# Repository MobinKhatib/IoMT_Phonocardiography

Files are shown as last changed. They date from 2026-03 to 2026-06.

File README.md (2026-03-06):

# IoMT_Phonocardiography
Laboratory of Internet of Medical Things

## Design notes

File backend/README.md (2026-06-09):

# PCG BLE Client

Python client for collecting phonocardiogram (PCG) data from Arduino via BLE.

## Installation

```bash
python3 -m venv venv
source venv/bin/activate
pip install -r requirements.txt
```

## Usage

```python
import asyncio
from pcg_ble_client import PCGClient

async def main():
    client = PCGClient(device_name="PCG_Monitor_Raw")
    await client.connect()

    # Collect 60 seconds of data
    async for batch in client.analyze(sample_rate=500, oversample_count=8, batch_size=6,
                               patient_name="John", analysis_time_seconds=60):
        print(f"Got batch: {batch}")

    # Get full accumulated signal
    signal = client.get_full_signal()

    await client.disconnect()

asyncio.run(main())
```

## API

### `PCGClient`

#### `connect()`
Establish BLE connection to Arduino.

#### `disconnect()`
Close BLE connection.

#### `is_connected() -> bool`
Check connection status.

#### `analyze(...) -> Generator[np.ndarray]`
Send analysis request and yield batches.

Parameters:
- `sample_rate` (int): Hz
- `oversample_count` (int): ADC reads per sample
- `batch_size` (int): Samples per BLE packet
- `patient_name` (str): Patient ID (truncated to 15 chars)
- `analysis_time_seconds` (int): Collection duration

Yields: `np.ndarray` of samples (uint16)

#### `get_full_signal() -> np.ndarray`
Return all accumulated samples (validated).

## Running Tests

```bash
python3 -m pytest tests/ -v
```

## Integration Tests

Integration tests require Arduino with `ble_lcd_analyzer.ino` flashed and powered.

```bash
pytest tests/test_integration.py -v -m "asyncio"
```

Note: Tests will skip if Arduino is not available.

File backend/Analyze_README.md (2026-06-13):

# PCG Analysis Pipeline (`pcg_pipeline.py`)

A Python pipeline that converts a raw WAV phonocardiogram (PCG) recording into structured, JSON-serialisable analysis data — covering signal cleaning, heart sound segmentation, cycle-level feature extraction, anomaly detection, and murmur grading.

---

## Table of contents

1. [What this pipeline does](#1-what-this-pipeline-does)
2. [Quick start](#2-quick-start)
3. [Dependencies](#3-dependencies)
4. [Configuration (`PCGConfig`)](#4-configuration-pcgconfig)
5. [Processing stages explained](#5-processing-stages-explained)
6. [Heart metrics explained](#6-heart-metrics-explained)
7. [Output schema](#7-output-schema)
8. [CLI usage](#8-cli-usage)
9. [WebUI integration](#9-webui-integration)
10. [Performance guidance](#10-performance-guidance)

---

## 1) What this pipeline does

`pcg_pipeline.py` takes a mono WAV file (typically 500 Hz, recorded from an ESP32 microphone) and runs it through five modules:

| Module | Output |
| --- | --- |
| Signal preprocessing | Clean, noise-reduced waveform |
| Envelope + peak detection | S1 and S2 heart sound locations |
| Segmentation | Sample-level labels: S1 / Systole / S2 / Diastole |
| Feature extraction + classification | Per-cycle metrics, rule-based checks, Isolation Forest anomaly scores |
| Murmur analysis | Per-cycle murmur flags and a summary assessment |

All outputs are plain Python types (no NumPy) so the returned dict can be passed directly to `json.dumps`.

---

## 2) Quick start

```python
from pcg_pipeline import run_pcg_pipeline, PCGConfig

result = run_pcg_pipeline(
    filename="/path/to/recording.wav",
    config=None,               # optional PCGConfig — defaults are fine for 500 Hz recordings
    save_filtered_wav=False,   # True → write <input>_filtered.wav to disk
    output_filename=None,      # custom path for the filtered WAV
    include_signals=False,     # True → add raw/filtered/envelope arrays to the result
)
```

Alias (identical behaviour):

```python
from pcg_pipeline import run_pipeline
result = run_pipeline("/path/to/recording.wav", include_signals=True)
```

---

## 3) Dependencies

```text
numpy
scipy
PyWavelets
librosa
scikit-learn
```

Install:

```bash
pip install numpy scipy PyWavelets librosa scikit-learn
```

---

## 4) Configuration (`PCGConfig`)

Pass a `PCGConfig` instance to override any default. Defaults are tuned for ESP32 recordings at 500 Hz.

| Field | Default | Meaning |
| --- | --- | --- |
| `lowcut` | `25.0` | Bandpass lower cutoff (Hz) — captures the full S1 fundamental |
| `highcut` | `200.0` | Bandpass upper cutoff (Hz) — auto-clamped to `Nyquist - 1` |
| `notch_freqs` | `(50.0, 100.0, 150.0)` | Powerline hum frequencies to notch out (Hz) |
| `notch_q` | `35.0` | Q-factor for each notch (higher = narrower notch) |
| `filter_order` | `4` | Butterworth bandpass order |
| `wavelet` | `"db6"` | Wavelet family for DWT denoising |
| `wavelet_level` | `4` | Decomposition depth |
| `envelope_cutoff` | `8.0` | Lowpass cutoff for Shannon envelope smoothing (Hz) |
| `min_peak_dist` | `0.25` | Minimum time between detected peaks (seconds) |
| `bpm_min` | `40` | Physiological HR lower bound (reserved for future gating) |
| `bpm_max` | `200` | Physiological HR upper bound (reserved for future gating) |
| `normal_ranges` | see below | Rule-based physiological limits per metric |
| `murmur_grade_thresholds` | `[0.15, 0.30, 0.50, 0.70, 0.90]` | Energy-ratio thresholds for murmur grading |

Default `normal_ranges`:

```python
{
    "s1_duration_ms":  (50, 200),
    "s2_duration_ms":  (40, 150),
    "systolic_ms":     (150, 450),
    "diastolic_ms":    (150, 1200),
    "s1_s2_amp_ratio": (0.5, 3.0),
    "heart_rate_bpm":  (45, 180),
}
```

---

## 5) Processing stages explained

### Stage 1 — DC offset removal

```
data = data - mean(data)
```

Removes any constant voltage offset introduced by the ADC or BLE transmission path. Must happen before filtering to avoid distortion.

### Stage 2 — Multi-notch filter

Three narrow IIR notch filters are applied sequentially at 50 Hz, 100 Hz, and 150 Hz (fundamental powerline frequency plus its two lowest harmonics). Q = 35 keeps each notch very narrow so heart-sound energy at adjacent frequencies is untouched. Any notch above Nyquist is skipped automatically.

### Stage 3 — Bandpass filter (25–200 Hz)

A zero-phase 4th-order Butterworth bandpass keeps only the frequency range that contains S1 and S2 energy and rejects low-frequency motion artefacts and high-frequency noise above the heart-sound band. The upper cutoff is clamped to `Nyquist - 1` automatically.

### Stage 4 — Wavelet denoising

Daubechies-6 (db6) discrete wavelet transform, 4 levels. A soft threshold is applied to all detail coefficients using a scaled Donoho-Johnstone universal threshold:

```
uthresh = 0.6 × σ × sqrt(2 × log(N))
```

The scale factor 0.6 (versus the classical value of 1.0) is intentional: it preserves more fine structure in the heart sounds while still suppressing broadband noise. σ is estimated from the finest-level coefficients via MAD.

### Stage 5 — Savitzky-Golay smoothing

A window-11, polynomial-order-3 SG filter removes any residual sample-level jitter while preserving peak sharpness. Final output is `filtered`.

### Stage 6 — Shannon energy envelope

```
E[n] = -x[n]² · log(x[n]² + ε)
```

Shannon energy suppresses low-amplitude noise more aggressively than simple squaring and gives better S1/S2 contrast. The result is lowpass-filtered at 8 Hz to produce a smooth envelope.

### Stage 7 — Peak detection and S1/S2 classification

`scipy.signal.find_peaks` is applied to the envelope with an adaptive threshold at the 75th percentile. Peaks are then classified as S1 or S2 using the interval-ratio rule: systole (S1→S2) is always shorter than diastole (S2→next S1), so consecutive triplets of peaks are labelled by which gap is shorter.

### Stage 8 — Segmentation

Sample-level state labels (0=S1, 1=Systole, 2=S2, 3=Diastole) are assigned by:
- Growing S1/S2 boundaries outward from each peak to 40% of peak height
- Filling the gap between S1-end and the next S2-start as Systole (if < 400 ms)
- Filling the gap between S2-end and the next S1-start as Diastole

---

## 6) Heart metrics explained

This section describes every metric the pipeline produces and what it means clinically.

### 6.1 Timing intervals

| Metric | Key | Normal range | Meaning |
| --- | --- | --- | --- |
| S1 duration | `s1_duration_ms` | 50–200 ms | Width of the first heart sound. S1 is caused by closure of the mitral and tricuspid valves at the start of ventricular contraction. Too short can indicate a sharp, pathological snap; too long may suggest a prolonged closure sequence. |
| S2 duration | `s2_duration_ms` | 40–150 ms | Width of the second heart sound. S2 is caused by closure of the aortic and pulmonary valves at the end of systole. A split S2 (audible doubling) can appear as an abnormally long or double-peaked S2. |
| Systolic interval | `systolic_ms` | 150–450 ms | Time from S1 start to S2 start. This is the period of ventricular ejection. Normal adult systole at rest is ~300 ms. Prolonged systole may suggest impaired ventricular function. |
| Diastolic interval | `diastolic_ms` | 150–1200 ms | Time from S2 start to next S1 start. Diastole is the filling phase. It is longer than systole at normal resting heart rates and shortens as rate increases. Very short diastole at high heart rates may limit filling time. |
| Cycle duration | `cycle_duration_ms` | derived | Full S1-to-S1 period in ms. Reciprocal gives heart rate. |
| Heart rate | `heart_rate_bpm` | 45–180 bpm | Beats per minute derived from cycle duration. Normal adult resting range is 60–100 bpm. |
| S:D ratio | `sd_ratio` | ~0.4–0.7 | Systolic interval divided by diastolic interval. At 60 bpm this is roughly 0.5. Rising ratio (diastole shrinking relative to systole) occurs at high heart rates or with prolonged ventricular contraction. |

### 6.2 Amplitude features

| Metric | Key | Meaning |
| --- | --- | --- |
| S1 RMS | `s1_rms` | Root-mean-square amplitude of the S1 segment. Reflects how loud the mitral/tricuspid closure is in the recording. |
| S2 RMS | `s2_rms` | Root-mean-square amplitude of the S2 segment. |
| S1/S2 amplitude ratio | `s1_s2_amp_ratio` | S1 RMS divided by S2 RMS. Normal range 0.5–3.0. A ratio < 0.5 (S2 louder than S1) at the apex may indicate aortic regurgitation. A very high ratio may reflect a soft S2. |
| Energy concentration | `energy_concentration` | Fraction of the full-cycle energy contained in the S1 and S2 segments. A healthy heart concentrates energy in the valve closures; a murmur spreads energy into systole or diastole. |
| Systolic noise ratio | `sys_noise_ratio` | RMS of the systolic segment divided by S1 RMS. Low values (< 0.15) indicate a quiet systole. Elevated values suggest systolic murmur energy. |
| Diastolic noise ratio | `dia_noise_ratio` | RMS of the diastolic segment divided by S1 RMS. Same interpretation for the diastolic phase. |

### 6.3 Spectral and waveform shape features

| Metric | Key | Meaning |
| --- | --- | --- |
| S1/S2 zero-crossing rate | `s1_zcr`, `s2_zcr` | Rate of sign changes per sample. A high ZCR indicates a noisy or multi-component sound; a low ZCR indicates a smoother, more tonal segment. |
| S1/S2 excess kurtosis | `s1_kurtosis`, `s2_kurtosis` | Statistical "peakedness" of the amplitude distribution. A sharp impulsive sound (like a clean valve closure) has high kurtosis. Broad or noisy segments have lower kurtosis. |
| S1/S2 spectral centroid | `s1_centroid`, `s2_centroid` | Frequency-weighted centre of mass of the FFT magnitude spectrum (Hz). S1 typically centres around 50–100 Hz; S2 slightly higher. An elevated centroid may indicate high-frequency murmur contamination of the sound. |
| MFCC means | `mfcc_0` … `mfcc_7` | Mean of 8 Mel-frequency cepstral coefficients computed over the full cycle. MFCCs capture the spectral envelope shape and are used as input features for the Isolation Forest classifier. They do not have a direct single-value clinical interpretation but collectively encode the timbral character of the cycle. |

### 6.4 Heart rate variability (HRV)

Computed from the sequence of RR intervals (cycle durations) across the whole recording. Only cycles with durations between 300 ms and 1500 ms are included.

| Metric | Key | Meaning |
| --- | --- | --- |
| Mean heart rate | `heart_rate_mean_bpm` | Average BPM across valid cycles. |
| HR standard deviation | `heart_rate_std_bpm` | Beat-to-beat variability of heart rate (BPM). |
| SDNN | `sdnn_ms` | Standard deviation of all NN (normal-to-normal) intervals. Captures overall HRV. Values < 20 ms suggest reduced autonomic modulation. |
| RMSSD | `rmssd_ms` | Root mean square of successive RR differences. Reflects short-term, predominantly parasympathetic (vagal) variability. Healthy adults at rest typically show 20–60 ms. |
| pNN50 | `pnn50_pct` | Percentage of consecutive RR differences > 50 ms. A higher pNN50 indicates greater parasympathetic tone. |

### 6.5 Murmur grading

Each cardiac cycle is independently assessed for murmur energy.

**Detection**: the RMS of the systolic (or diastolic) interval is compared to S1 RMS. If the ratio exceeds the first threshold (0.15 by default) the cycle is flagged.

**Grading** uses an energy-ratio approximation of the Levine scale:

| Grade | Ratio range | Clinical description |
| --- | --- | --- |
| 0 | < 0.15 | No murmur |
| 1 | 0.15–0.30 | Barely audible, heard only in quiet conditions |
| 2 | 0.30–0.50 | Faint but clearly heard |
| 3 | 0.50–0.70 | Moderately loud |
| 4 | 0.70–0.90 | Loud |
| 5–6 | > 0.90 | Very loud, may be audible with stethoscope partially off chest |

**Murmur shape features** (computed when the segment is long enough):

- `sys_diamond`: `True` if the envelope of the systolic segment peaks in the middle quarter of the interval. A diamond (crescendo-decrescendo) shape is characteristic of aortic stenosis and other ejection murmurs.
- `dia_decrescendo`: `True` if the first quarter of the diastolic envelope is more than 1.5× louder than the last quarter. A decrescendo shape is characteristic of aortic regurgitation.

**Summary assessment** (from `murmur.assessment`):

| Condition | Text |
| --- | --- |
| > 50% cycles flagged in either phase | "Significant murmur activity …" |
| 20–50% cycles flagged | "Some murmur-like activity detected (may be recording noise)" |
| < 20% cycles flagged | "No significant murmur activity" |

### 6.6 Anomaly detection (Isolation Forest)

All per-cycle features (excluding the private `_start`/`_end` indices) are z-scored and fed to an Isolation Forest with 200 trees and a 15% contamination prior. Each cycle receives:

- `label`: `1` = normal, `-1` = anomaly
- `score`: decision function value (more negative = more anomalous)

An anomalous cycle does not necessarily mean disease — it may reflect a position shift during recording, a deep breath, or an ectopic beat. Use it as a flag for human review rather than a diagnosis.

---

## 7) Output schema

`run_pcg_pipeline(...)` returns a dict with these top-level keys.

### 7.1 `file_info`

```json
{
  "filename": "/path/to/recording.wav",
  "sample_rate_hz": 500,
  "nyquist_hz": 250.0,
  "duration_s": 23.0,
  "samples": 11510,
  "highcut_clamped": false,
  "effective_highcut_hz": 200.0
}
```

### 7.2 `config`

The full `PCGConfig` serialised as a dict, so the consumer knows exactly what parameters were used.

### 7.3 `peaks`

```json
{
  "total_peaks": 54,
  "s1_count": 31,
  "s2_count": 31,
  "peak_indices": [...],
  "s1_indices": [...],
  "s2_indices": [...],
  "peak_times_s": [...],
  "s1_times_s": [...],
  "s2_times_s": [...],
  "threshold": 0.042
}
```

### 7.4 `segmentation`

```json
{
  "state_names": ["S1", "Systole", "S2", "Diastole"],
  "states": [3, 3, 0, 0, 1, 1, ...],
  "segments": [
    {"state": "S1", "start_index": 120, "end_index": 164, "start_s": 0.24, "end_s": 0.328},
    ...
  ],
  "stats": {
    "S1":       {"count": 20, "mean_ms": 88.4, "std_ms": 26.2, "min_ms": 46, "max_ms": 128},
    "Systole":  {"count": 22, "mean_ms": 231.8, ...},
    "S2":       {"count": 28, "mean_ms": 85.3, ...},
    "Diastole": {"count": 29, "mean_ms": 474.6, ...}
  }
}
```

### 7.5 `classification`

```json
{
  "cycles": [
    {
      "s1_duration_ms": 98.0,
      "s2_duration_ms": 82.0,
      "systolic_ms": 302.0,
      "diastolic_ms": 520.0,
      "cycle_duration_ms": 820.0,
      "heart_rate_bpm": 73.2,
      "sd_ratio": 0.58,
      "s1_rms": 0.045,
      "s2_rms": 0.068,
      "s1_s2_amp_ratio": 0.66,
      "energy_concentration": 0.71,
      "s1_zcr": 0.32,
      "s2_zcr": 0.29,
      "s1_kurtosis": 2.1,
      "s2_kurtosis": 1.8,
      "s1_centroid": 78.4,
      "s2_centroid": 91.2,
      "sys_noise_ratio": 0.09,
      "dia_noise_ratio": 0.07,
      "mfcc_0": -12.4,
      "mfcc_1": 3.1,
      "...": "...",
      "_s1_start": 120, "_s1_end": 164,
      "_sys_start": 164, "_sys_end": 315,
      "_s2_start": 315, "_s2_end": 356,
      "_dia_start": 356, "_dia_end": 616
    }
  ],
  "rule_based": {
    "normal_cycles": 20,
    "flagged_cycles": 8,
    "flagged_details": [
      {"cycle_index": 0, "violations": ["s1_s2_amp_ratio=0.5 < 0.5"]}
    ]
  },
  "isolation_forest": {
    "feature_keys": ["s1_duration_ms", "s2_duration_ms", ...],
    "labels": [1, 1, -1, 1, ...],
    "scores": [0.08, 0.06, -0.05, ...],
    "normal_cycles": 23,
    "anomaly_cycles": 5,
    "score_min": -0.053,
    "score_max": 0.100
  },
  "per_cycle_stats": {
    "heart_rate_bpm": {"mean": 73.2, "std": 4.3, "min": 55.7, "max": 78.7},
    "...": "..."
  },
  "hrv_metrics": {
    "heart_rate_mean_bpm": 73.2,
    "heart_rate_std_bpm": 4.3,
    "sdnn_ms": 57.5,
    "rmssd_ms": 88.6,
    "pnn50_pct": 35.7
  }
}
```

`hrv_metrics` is `null` if fewer than 3 valid RR intervals are found.

Private keys (`_s1_start`, etc.) in each cycle dict hold sample indices for span rendering. They are not included in the Isolation Forest feature matrix.

### 7.6 `murmur`

```json
{
  "analysis_range_hz": [0.0, 250.0],
  "systolic_murmur_cycles": 7,
  "diastolic_murmur_cycles": 8,
  "total_cycles": 28,
  "systolic_pct": 25.0,
  "diastolic_pct": 28.6,
  "assessment": "Some murmur-like activity detected (may be recording noise)",
  "cycle_results": [
    {
      "systolic_murmur": true,
      "diastolic_murmur": false,
      "systolic_grade": 1,
      "diastolic_grade": 0,
      "systolic_ratio": 0.19,
      "diastolic_ratio": 0.08,
      "sys_diamond": false
    }
  ]
}
```

`sys_diamond` and `dia_decrescendo` only appear when the respective segment is long enough to compute them.

### 7.7 `exports`

```json
{
  "saved_filtered_wav": "/path/to/recording_filtered.wav"
}
```

`null` when `save_filtered_wav=False`.

### 7.8 `signals` (optional, `include_signals=True` only)

```json
{
  "time_axis_s": [...],
  "raw": [...],
  "filtered": [...],
  "filtered_normalized": [...],
  "envelope": [...]
}
```

---

## 8) CLI usage

```bash
cd Analysis
python pcg_pipeline.py /path/to/recording.wav
python pcg_pipeline.py /path/to/recording.wav --save-filtered
python pcg_pipeline.py /path/to/recording.wav --include-signals
```

Output is printed as indented JSON to stdout.

---

## 9) WebUI integration

### Backend

1. Receive WAV upload, save to a temp file.
2. Call `run_pcg_pipeline(filename, include_signals=True)`.
3. Return JSON to frontend.

Use `include_signals=False` for a lightweight summary endpoint and `include_signals=True` for a full chart endpoint.

### Frontend chart layers

| Plot | x-axis | y / spans |
| --- | --- | --- |
| Waveform + envelope | `signals.time_axis_s` | `signals.filtered` and `signals.envelope` |
| S1/S2 markers | `peaks.s1_times_s`, `peaks.s2_times_s` | points on envelope |
| Segmentation | `segmentation.segments[i].start_s` → `end_s` | coloured spans: S1=red, Systole=orange, S2=blue, Diastole=green |
| Anomaly overlay | `cycles[i]._s1_start / sample_rate` → `_dia_end / sample_rate` | green (label=1) or red (label=-1) |
| Murmur overlay | `cycles[i]._sys_start / sample_rate` → `_sys_end / sample_rate` | red when `systolic_murmur=true` |
| Murmur overlay | `cycles[i]._dia_start / sample_rate` → `_dia_end / sample_rate` | purple when `diastolic_murmur=true` |

---

## 10) Performance guidance

Long recordings produce large signal arrays. Downsample only the waveform for display; keep all event data at full precision.

```python
import numpy as np

def decimate_xy(x, y, max_points=3000):
    n = len(x)
    if n <= max_points:
        return x, y
    idx = np.linspace(0, n - 1, max_points, dtype=int)
    return [x[i] for i in idx], [y[i] for i in idx]
```

Target 2 000–5 000 points per chart line. All segment/peak/label arrays can remain at full length since they are small.

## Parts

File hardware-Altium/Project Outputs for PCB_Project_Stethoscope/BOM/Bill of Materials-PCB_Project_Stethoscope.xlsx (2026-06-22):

Line # | Name | Description | Designator | Quantity | Manufacturer 1 | Manufacturer Part Number 1 | Manufacturer Lifecycle 1 | Supplier 1 | Supplier Part Number 1 | Supplier Unit Price 1 | Supplier Subtotal 1
 | 100u | capacitor | C1 | 1 | Panasonic | EEEFTH100UAR | Volume Production | RS | 7296283P | 0.13308 | 13.31
 | 10u | capacitor | C2 | 1 | KYOCERA AVX | 1206ZD106KAT2A | Volume Production | Avnet | KGM31HR51A106KU | 0.32544 | 650.88
 | MDOB048064AV-WI | LED | IC1 | 1 | Midas | MDOB048064AV-WI |  | Farnell | MDOB048064AV-WI | 11.12 | 11.12
 | JST-PH 2-pin Battery Connector | JST-PH 2-pin LiPo Battery Connector | J1 | 1 | Adafruit Industries | 4714 |  | DigiKey | 1528-4714-ND | 0.95 | 0.95
 | 2.2k | Resistor | R1, R2 | 2 | KOA Speer | RN73R2ATTD2201B10 | Volume Production | RS | 2050472 | 0.80307 | 8.03
 | Arduino Nano ESP 32 |  | U1 | 1 | Arduino | ABX00092 |  | Farnell | ABX00092 | 18.17 | 18.17
 | SEN-14262 | Audio sensor | U2 | 1 | SparkFun | SEN-14262 |  | Arrow Electronics | SEN-14262
 | USB-C Charger Module | ADAFRUIT 4410 MICROLIPO USBC MODULE | U3 | 1 | Adafruit Industries | 4410 |  | DigiKey | 1528-4410-ND | 5.95 | 5.95

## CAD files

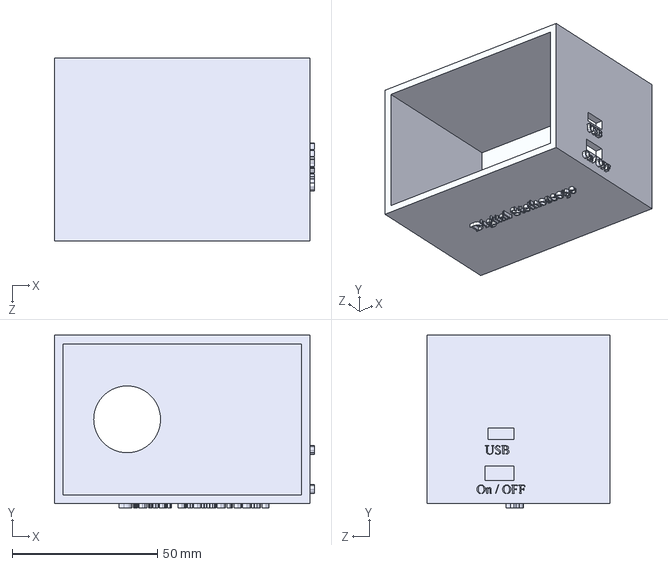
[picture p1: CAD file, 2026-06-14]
design/Digital Stethoscope Box3D/Part1.STEP
89.5 x 59.5 x 63.0 mm

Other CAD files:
design/Digital Stethoscope Box3D/Part1.SLDPRT
design/Digital Stethoscope Box3D/Part1.STL
design/Digital Stethoscope Box3D/Part2.SLDPRT
design/Digital Stethoscope Box3D/Part2.STL

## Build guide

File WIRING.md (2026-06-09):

# Arduino Nano ESP32 Wiring Guide

## Components Required

| Component | Part Number | Notes |
|---|---|---|
| Arduino Nano ESP32 | AE-ESP32-S3 | Main microcontroller |
| OLED Display | SSD1306 48x64 | I2C interface |
| LiPo Battery | 3.7V or 4.2V | Recommended 2000-5000 mAh |
| Phonocardiography Sensor | Analog output | ADC input |
| Resistor 2.2kΩ | (2x) | Battery voltage divider |
| Resistor 2.2kΩ | 1x | Optional pull-up for sensor |
| Capacitor 100µF | 1x | Power supply decoupling |
| Capacitor 10µF | 1x | Filter for battery line |

---

## Pinout Reference (Arduino Nano ESP32)

```
┌──────────────────────────────────────────┐
│      ARDUINO NANO ESP32 (Top View)       │
├──────────────────────────────────────────┤
│  D0/RX   GND   RESET  AREF   A0         │
│  D1/TX   GND    VIN    3V3   A1         │
│                                          │
│  D2      D3     D4     D5    D6          │
│  D7      D8     D9    D10   D11          │
│                                          │
│  D12    D13    GND    5V    RST          │
│  A2     A3    A4/SDA  A5/SCL            │
│         A6     A7     GND               │
│                                          │
│ I2C Default: SDA=A4(pin12)  SCL=A5(pin13)
│ Signal Input: A0 (pin19)                │
│ Battery Input: A1 (pin20)               │
└──────────────────────────────────────────┘
```

---

## Connection Diagram

### 1. OLED Display (SSD1306 I2C)

**Display Pins (Arduino Nano ESP32):**
- **GND** → Arduino Nano ESP32 GND
- **VCC** → Arduino Nano ESP32 3V3
- **SCL** → Arduino Nano ESP32 **A5** (pin 13)
- **SDA** → Arduino Nano ESP32 **A4** (pin 12)

```
     ┌──────────────────────┐
     │   SSD1306 OLED       │
     │   (48x64 pixels)     │
     └──────────────────────┘
            │    │    │    │
           GND  VCC  SCL  SDA
            │    │    │    │
            ↓    ↓    ↓    ↓
        GND  3V3 D4   D5
        ESP32 NANO
```

**Schematic Detail:**
```
3V3 ──────┬────────→ VCC (OLED)
          │
        100µF cap (ground other end)
          │
        GND

D4 (GPIO4/SCL) ──→ SCL (OLED)
D5 (GPIO5/SDA) ──→ SDA (OLED)

GND ──→ GND (OLED)
```

---

### 2. Battery Voltage Monitor (A0)

**Setup: 2:1 Voltage Divider**
- Monitor battery voltage to calculate percentage
- Supports 3.3V to 4.2V (LiPo) range
- **SEPARATE from signal input** (A0 dedicated to battery only)

```
        LiPo Battery (4.2V max)
        │
        │ (+ terminal)
        ├──────────────────→ (to system power, ~5V input)
        │
        ├──[2.2kΩ resistor]──┬──→ A0 (ADC, Battery Monitor)
        │                     │
        └────────────────────┴──[2.2kΩ resistor]──→ GND
                             │
                         (midpoint = A0 input)
```

**Voltage Divider Math:**
- Vin = 4.2V (fully charged LiPo)
- Vout = Vin × (R2 / (R1 + R2)) = 4.2 × (2.2k / 4.4k) = 2.1V
- ADC reads 2.1V at 12-bit resolution: (2.1 / 3.3) × 4095 ≈ 2613 counts
- Code maps: 3.3V (0%) → 4.2V (100%)

**Capacity Calculation (in code):**
```cpp
uint32_t mv = analogReadMilliVolts(A0);
mv /= 16;  // Average 16 samples
float vbat = mv * 2.0 / 1000.0;  // × 2 for divider
int pct = (int)((vbat - 3.3) / (4.2 - 3.3) * 100.0);
```

---

### 3. Phonocardiography Sensor Input (A1)

**Analog Signal Path:**
- **Sensor Output** → 10µF capacitor → **A1** (separate from battery A0)
- Optional: 2.2kΩ pull-up to 3V3 for impedance matching

```
    Phonocardiography Sensor
    (analog output, 0-3.3V)
           │
           ├──[10µF cap]──┬──→ A1 (ADC, Signal Input)
           │              │
           └──────────────┴──→ GND
                          
    (Optional pull-up for high-impedance sensors)
           ├──[2.2kΩ]──→ 3V3
```

**Why separate pins?**
- A0 dedicated to battery monitoring (always active)
- A1 dedicated to signal sampling (during analysis)
- Prevents interference between battery and signal readings

**ADC Configuration (in code):**
```cpp
analogReadResolution(12);  // 12-bit resolution (0-4095 counts)
```

---

## Full System Schematic

```
                    ┌─────────────────┐
                    │  LiPo Battery   │
                    │   3.7-4.2V      │
                    │ (2000-5000 mAh) │
                    └────────┬────────┘
                             │
                    ┌────────┴────────────────┐
                    │                         │
              [Voltage Divider]          [Power]
              (2.2k/2.2k)                 │
                    │                     │
                    ↓                     ↓
                  A0 (Battery)        +5V (VBAT)
                    │                     │
            ┌───────┴─────┬───────────────┴────────┐
            │             │                        │
        ┌─────────────────────────────────┐   ┌─────────────┐
        │     ESP32-S3 NANO               │   │   100µF     │
        │                                 │   │   Capacitor │
        │  D4 ──────────┬─────────────────┼───┤ (decouple)  │
        │  D5 ──────────┤                 │   └─────┬───────┘
        │               │ (I2C for OLED)  │         │
        │  A0 ←─ Battery Divider          │      GND
        │  A1 ←─ PCG Sensor               │
        │  3V3 ──────────┘                │
        │  GND ──────────────────┬────────┘
        │                        │
        └────────────┬───────────┘
                     │
        ┌────────────┴────────────┐
        │                         │
    ┌─────────────────┐   ┌──────────────────┐
    │  SSD1306 OLED   │   │  PCG Sensor      │
    │  (48x64 display)│   │  (Analog Out)    │
    │                 │   │                  │
    │  SCL ← D4       │   │  OUT ──[10µF]──┐ │
    │  SDA ← D5       │   │                 │ │
    │  VCC ← 3V3      │   │  GND ───────────┼─┘
    │  GND ─────────┐ │   │                 │
    │              │ │   │              GND
    └──────────────┼─┘   └────────┬────────┘
                  │                │
                  └────────┬───────┘
                           │
                  GND (common return)

Key: A0=Battery  A1=Signal  D4=SCL  D5=SDA
```

---

## Assembly Steps

1. **Battery Connection**
   - Connect LiPo + terminal → voltage divider upper end
   - Connect voltage divider center → A0
   - Connect voltage divider lower end → GND
   - Connect LiPo ground → ESP32 GND

2. **Power Decoupling**
   - 100µF capacitor across +5V and GND (near ESP32)
   - 10µF capacitor on sensor output (near A0)

3. **I2C Display (SSD1306)**
   - Connect SCL → GPIO4 (D4)
   - Connect SDA → GPIO5 (D5)
   - Connect 3V3 and GND

4. **Analog Sensor**
   - Connect sensor analog output through 10µF capacitor to A0
   - Ensure sensor is grounded to same GND

5. **Testing**
   - Flash `ble_lcd_analyzer.ino`
   - Check Serial Monitor (115200 baud)
   - Verify LCD shows battery % and "ADV" state
   - Confirm BLE device appears as "PCG_Monitor_Raw"

---

## Pin Usage Summary (Arduino Nano ESP32)

| Pin | Function | Used | Notes |
|-----|---|---|---|
| A0 (pin 19) | ADC Input | ✅ | Battery voltage divider (2:1) |
| A1 (pin 20) | ADC Input | ✅ | PCG sensor analog signal (10µF cap) |
| A4 (pin 12) | I2C SDA | ✅ | SSD1306 OLED display |
| A5 (pin 13) | I2C SCL | ✅ | SSD1306 OLED display |
| GND | Ground | ✅ | 2+ pins (battery, display, sensor) |
| 3V3 | Power 3.3V | ✅ | Display + logic |
| VIN/5V | Battery | ✅ | System power input |

---

## Power Budget

| Component | Current | Voltage | Power |
|---|---|---|---|
| ESP32-S3 | ~80 mA | 3.3V | 0.26W |
| OLED SSD1306 | ~10 mA | 3.3V | 0.03W |
| Sensor | ~5 mA | 3.3V | 0.02W |
| **Total** | **~95 mA** | **3.3V** | **~0.31W** |

**Runtime:** 2000 mAh battery ÷ 95 mA ≈ **21 hours** (nominal)

---

## Troubleshooting

**No Display:**
- Check I2C wiring (SDA/SCL swapped?)
- Verify 3V3 power to OLED
- Check Serial Monitor for I2C error messages

**No Sensor Data:**
- Verify A0 is not shorted
- Check sensor voltage is in 0-3.3V range
- Verify 10µF capacitor orientation (- to GND)

**Battery Reading Wrong:**
- Measure actual voltage at voltage divider midpoint
- Should be ~2.1V when battery is 4.2V
- Adjust resistor values if needed

**BLE Not Advertising:**
- Check Serial output: "BLE: Advertising started"
- Restart ESP32 if needed
- Ensure antenna connection (if external antenna model)

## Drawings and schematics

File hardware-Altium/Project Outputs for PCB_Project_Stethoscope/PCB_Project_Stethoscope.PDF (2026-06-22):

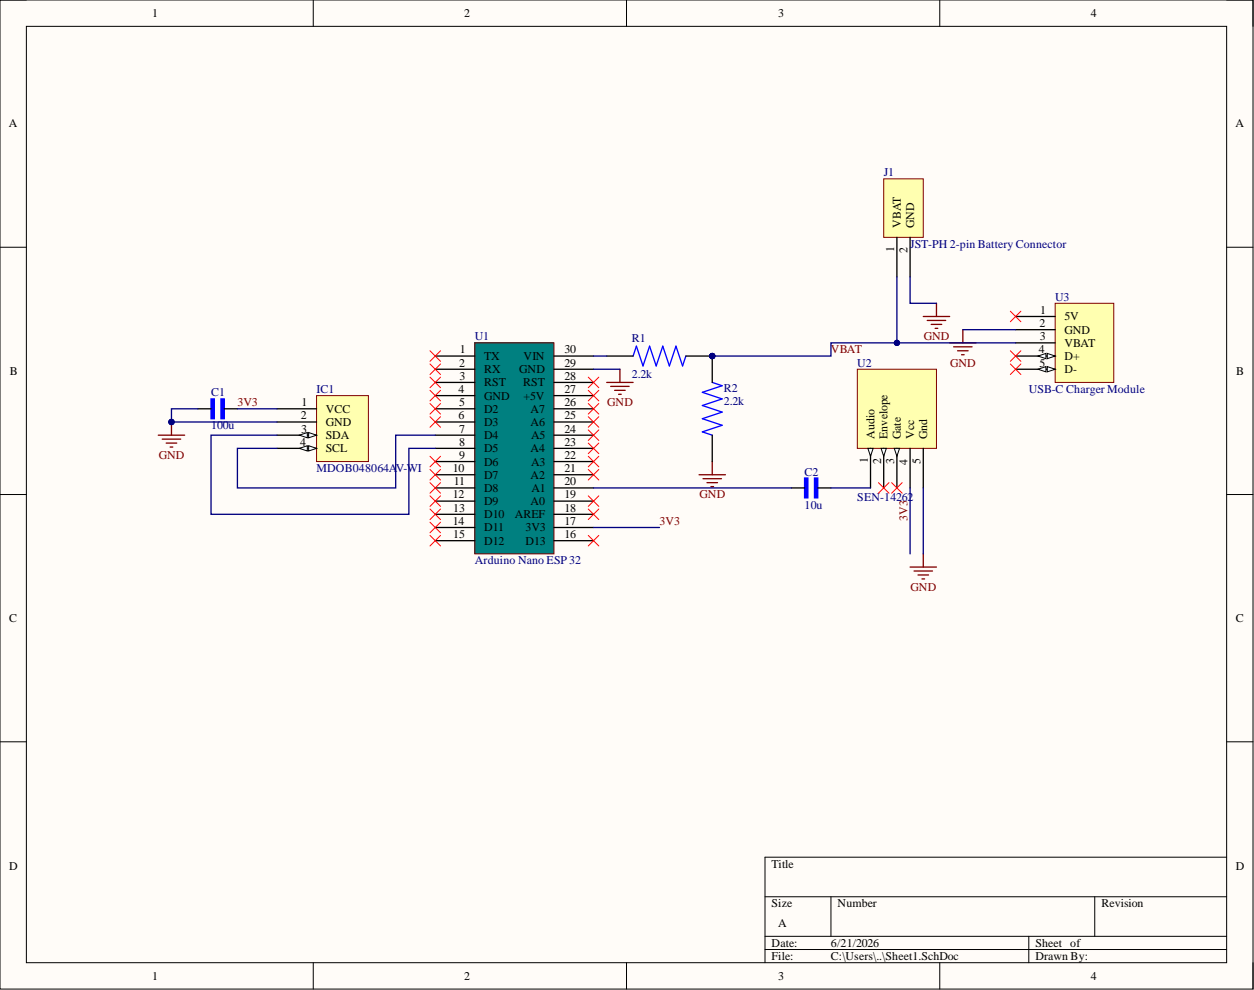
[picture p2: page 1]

JST-PH 2-pin Battery Connector

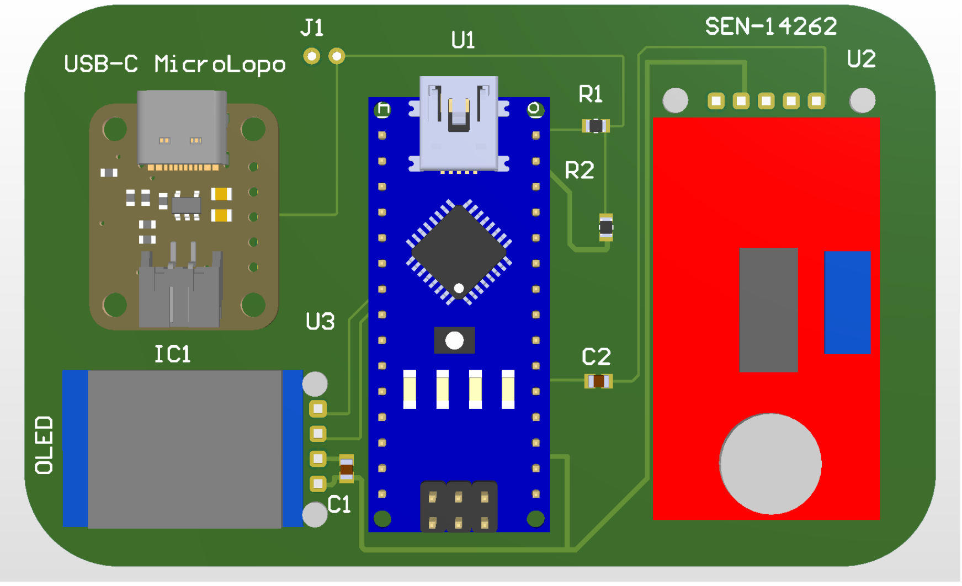
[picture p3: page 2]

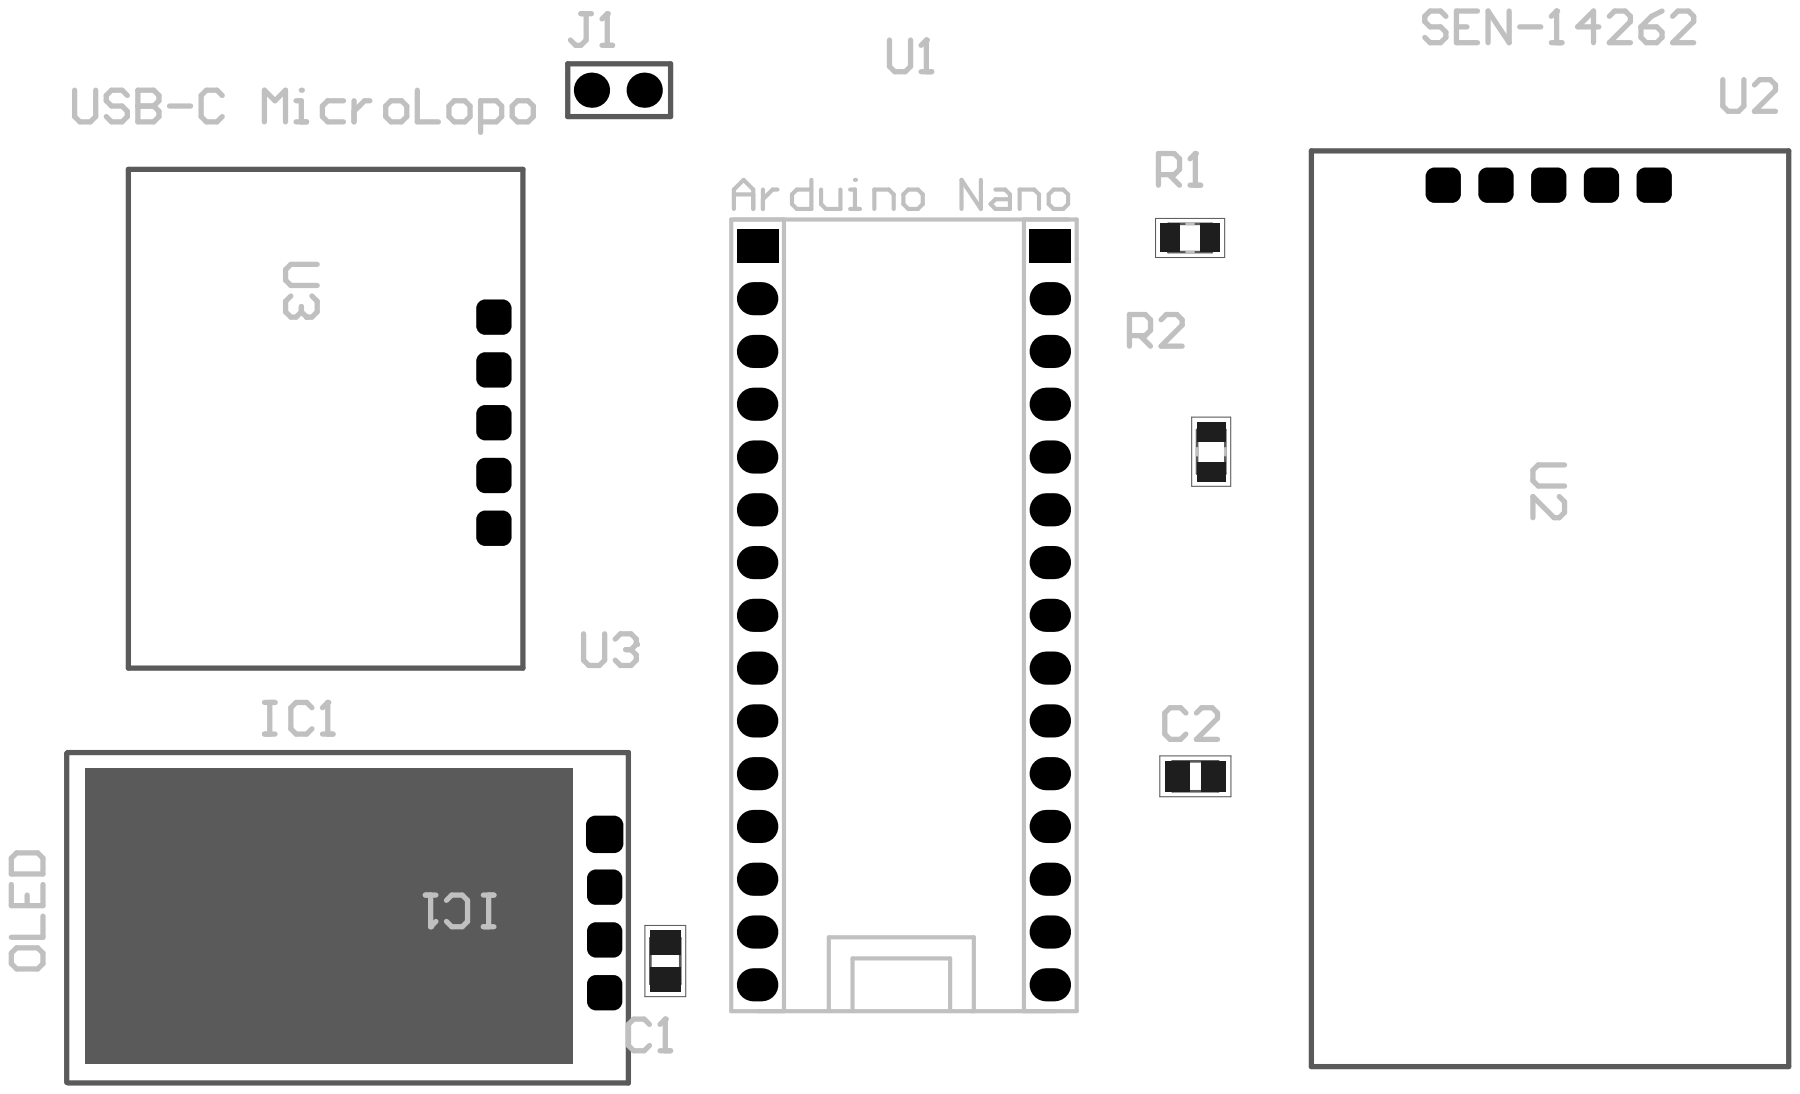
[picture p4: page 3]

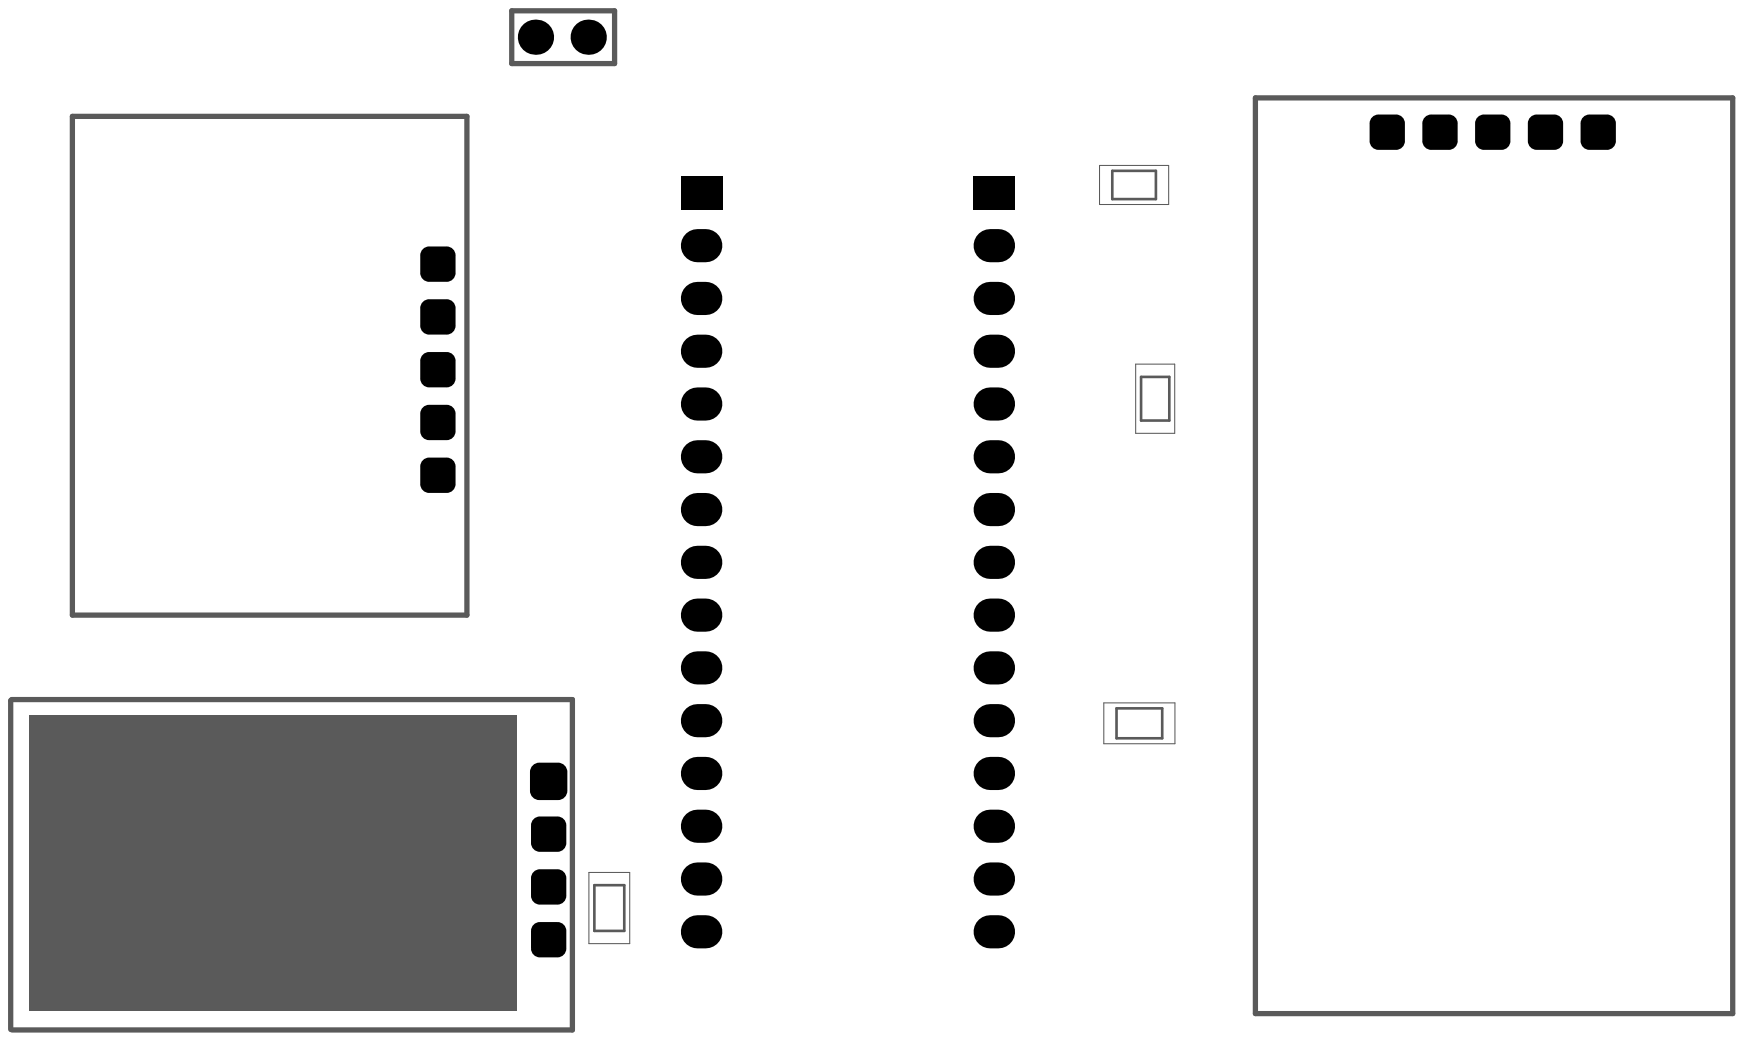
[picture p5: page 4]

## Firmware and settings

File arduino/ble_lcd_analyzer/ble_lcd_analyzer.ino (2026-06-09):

#include <BLEDevice.h>
#include <BLEServer.h>
#include <BLEUtils.h>
#include <BLE2902.h>
#include <U8g2lib.h>
#include <Wire.h>
#include <math.h>

// --- Configuration ---
const int BATTERY_PIN = A0;      // Battery voltage monitor (through divider)
const int SIGNAL_PIN = A1;       // PCG sensor analog input
const int TIMER_ID = 0;
const int TIMER_PRESCALER = 80;
const int TIMER_COUNT_UP = true;

// BLE UUIDs (from existing code)
#define SERVICE_UUID        "12345678-1234-1234-1234-123456789abc"
#define CHARACTERISTIC_UUID "abcd1234-ab12-cd34-ef56-123456789abc"

// Display (Arduino Nano ESP32: SCL=A5(pin13), SDA=A4(pin12))
U8G2_SSD1306_48X64_WINSTAR_F_HW_I2C u8g2(U8G2_R0, U8X8_PIN_NONE);

// --- State Machine ---
enum State {
  STATE_INITIALIZING,
  STATE_IDLE,
  STATE_CONNECTED,
  STATE_ANALYZING
};

State currentState = STATE_INITIALIZING;

// --- BLE ---
BLEServer* pServer = NULL;
BLECharacteristic* pCharacteristic = NULL;
bool deviceConnected = false;

// --- Sampling ---
#define MAX_BATCH_SIZE 6

// One completed batch of samples, passed from the sampling task to loop().
struct SampleBatch {
  uint16_t samples[MAX_BATCH_SIZE];
  uint8_t count;
};

hw_timer_t* timer = NULL;
TaskHandle_t samplingTaskHandle = NULL;
QueueHandle_t batchQueue = NULL;       // sampling task -> loop(); buffers batches so none are dropped
volatile bool resetSampling = false;   // signals the task to start a fresh run

int sampleRate = 500;
int oversampleCount = 8;
int batchSize = 6;
int analysisTimeSeconds = 60;
char patientName[16] = {0};

// --- Analysis Timer ---
unsigned long analysisStartTime = 0;
bool isAnalyzing = false;
bool shouldStartTimer = false;  // Flag to defer timer setup to main loop

// --- Battery Helper ---
int batteryPercent() {
  uint32_t mv = 0;
  for (int i = 0; i < 16; i++) mv += analogReadMilliVolts(BATTERY_PIN);
  mv /= 16;
  float vbat = mv * 2.0 / 1000.0;   // x2 for divider, mV -> V
  int pct = (int)((vbat - 3.3) / (4.2 - 3.3) * 100.0);
  return constrain(pct, 0, 100);
}

// --- Display Helpers ---
void drawBT(int cx, int ty) {
  int top = ty, bot = ty + 10, q1 = ty + 3, q3 = ty + 7;
  int r = cx + 3, l = cx - 3;
  u8g2.drawLine(cx, top, cx, bot);
  u8g2.drawLine(cx, top, r, q1);
  u8g2.drawLine(r, q1, l, q3);
  u8g2.drawLine(l, q1, r, q3);
  u8g2.drawLine(r, q3, cx, bot);
}

void drawCheck(int x, int y) {
  u8g2.drawLine(x, y + 2, x + 2, y + 4);
  u8g2.drawLine(x + 2, y + 4, x + 6, y - 1);
}

void textHighlight(int x, int y, int w, int h, const char* s, const uint8_t* font) {
  u8g2.drawBox(x, y, w, h);
  u8g2.setDrawColor(0);
  u8g2.setFont(font);
  u8g2.setCursor(x + 2, y + h - 2);
  u8g2.print(s);
  u8g2.setDrawColor(1);
}

void drawSpinner(int cx, int cy, int r) {
  u8g2.drawCircle(cx, cy, r);
  float a = millis() / 90.0;
  int sx = cx + (int)(cos(a) * r);
  int sy = cy + (int)(sin(a) * r);
  u8g2.drawDisc(sx, sy, 2);
}

void drawTopPanel() {
  u8g2.setFont(u8g2_font_5x7_tf);
  u8g2.setCursor(2, 10);
  u8g2.print("Bat:");
  u8g2.print(batteryPercent());
  u8g2.print("%");
  u8g2.drawHLine(0, 13, 48);
}

// --- Sampling Timer ISR ---
// IMPORTANT: On ESP32 you must NOT call analogRead() (or most driver/RTOS
// functions) from a hardware-timer ISR. analogRead() is not IRAM-safe and
// acquires locks, which aborts -> the board reboots the instant the timer
// fires. So the ISR only notifies the sampling task; the task does the reads.
void ARDUINO_ISR_ATTR onTimer() {
  BaseType_t higherPriorityTaskWoken = pdFALSE;
  vTaskNotifyGiveFromISR(samplingTaskHandle, &higherPriorityTaskWoken);
  portYIELD_FROM_ISR(higherPriorityTaskWoken);
}

// --- Sampling Task ---
// Runs in normal (non-ISR) context, so analogRead() is safe here. Wakes up
// once per timer tick, takes an oversampled reading, and fills the batch.
void samplingTask(void* param) {
  static SampleBatch batch;
  static int idx = 0;

  for (;;) {
    // Block until the timer ISR signals that it's time to take a sample.
    ulTaskNotifyTake(pdTRUE, portMAX_DELAY);

    // Start of a new analysis run: clear any partial batch and stale queue.
    if (resetSampling) {
      idx = 0;
      xQueueReset(batchQueue);
      resetSampling = false;
    }

    if (!isAnalyzing) {
      idx = 0;
      continue;
    }

    uint32_t sum = 0;
    for (int i = 0; i < oversampleCount; i++) {
      sum += analogRead(SIGNAL_PIN);  // Read from signal input, not battery
    }
    batch.samples[idx] = sum / oversampleCount;
    idx++;

    if (idx >= batchSize) {
      batch.count = batchSize;
      // Non-blocking hand-off to loop(). The queue buffers many batches so
      // samples are never dropped while loop() is busy with display or BLE.
      xQueueSend(batchQueue, &batch, 0);
      idx = 0;
    }
  }
}

// --- BLE Command Parsing ---
void parseStartCommand(uint8_t* data, size_t length) {
  if (length < 29) {
    Serial.println("BLE: Invalid packet length");
    return;
  }

  // Byte 0: command type (should be 0x01 for START)
  uint8_t cmdType = data[0];
  if (cmdType != 0x01) {
    Serial.println("BLE: Invalid command type");
    return;
  }

  // Bytes 1-4: SAMPLE_RATE (little-endian)
  sampleRate = (uint32_t)data[1] | ((uint32_t)data[2] << 8) | ((uint32_t)data[3] << 16) | ((uint32_t)data[4] << 24);
  sampleRate = constrain(sampleRate, 100, 5000);  // Limit to safe range

  // Bytes 5-6: OVERSAMPLE_COUNT (little-endian)
  oversampleCount = (uint16_t)data[5] | ((uint16_t)data[6] << 8);
  oversampleCount = constrain(oversampleCount, 1, 32);  // Limit to safe range

  // Bytes 7-8: BATCH_SIZE (little-endian)
  batchSize = (uint16_t)data[7] | ((uint16_t)data[8] << 8);
  batchSize = constrain(batchSize, 1, MAX_BATCH_SIZE);  // Limit to batch buffer size

  // Bytes 9-12: ANALYSIS_TIME_SECONDS (little-endian)
  analysisTimeSeconds = (uint32_t)data[9] | ((uint32_t)data[10] << 8) | ((uint32_t)data[11] << 16) | ((uint32_t)data[12] << 24);

  // Bytes 13-28: Patient name (null-terminated)
  memset(patientName, 0, sizeof(patientName));
  strncpy(patientName, (const char*)&data[13], 15);
  patientName[15] = '\0';

  Serial.print("BLE: START command - SR=");
  Serial.print(sampleRate);
  Serial.print(" OS=");
  Serial.print(oversampleCount);
  Serial.print(" BS=");
  Serial.print(batchSize);
  Serial.print(" Time=");
  Serial.print(analysisTimeSeconds);
  Serial.print(" Patient=");
  Serial.println(patientName);

  // Start analysis
  startAnalysis();
}

void startAnalysis() {
  isAnalyzing = true;
  analysisStartTime = millis();
  resetSampling = true;
  currentState = STATE_ANALYZING;
  shouldStartTimer = true;  // Defer timer setup to main loop
  Serial.println("Analysis started");
}

// --- BLE Callbacks ---
class ServerCallbacks : public BLEServerCallbacks {
  void onConnect(BLEServer* pServer) {
    deviceConnected = true;
    currentState = STATE_CONNECTED;
    Serial.println("BLE: Client connected");
  }
  void onDisconnect(BLEServer* pServer) {
    Serial.println("BLE: Client disconnected (onDisconnect callback triggered)");
    deviceConnected = false;
    isAnalyzing = false;
    currentState = STATE_IDLE;
    BLEDevice::startAdvertising();
  }
};

class CharacteristicCallbacks : public BLECharacteristicCallbacks {
  void onWrite(BLECharacteristic* pCharacteristic) {
    std::string value = pCharacteristic->getValue();
    if (value.length() > 0) {
      Serial.print("BLE: Received ");
      Serial.print(value.length());
      Serial.println(" bytes");
      parseStartCommand((uint8_t*)value.data(), value.length());
      Serial.println("BLE: Write processed successfully");
    }
  }
};

void updateDisplay() {
  u8g2.clearBuffer();
  drawTopPanel();

  switch (currentState) {
    case STATE_INITIALIZING: {
      u8g2.setFont(u8g2_font_5x7_tf);
      u8g2.setCursor(6, 34);
      u8g2.print("Starting");
      drawSpinner(24, 55, 6);
      break;
    }

    case STATE_IDLE: {
      if ((millis() / 400) % 2) drawBT(9, 20);
      u8g2.setFont(u8g2_font_5x7_tf);
      u8g2.setCursor(18, 30);
      u8g2.print("ADV");
      u8g2.setFont(u8g2_font_4x6_tf);
      u8g2.setCursor(2, 44);
      u8g2.print("advertising");
      break;
    }

    case STATE_CONNECTED: {
      drawBT(9, 20);
      drawCheck(34, 22);
      u8g2.setFont(u8g2_font_5x7_tf);
      u8g2.setCursor(18, 30);
      u8g2.print("CONN");
      textHighlight(2, 38, 46, 9, "connected", u8g2_font_4x6_tf);
      break;
    }

    case STATE_ANALYZING: {
      u8g2.setFont(u8g2_font_4x6_tf);
      u8g2.setCursor(2, 22);
      u8g2.print("User:");
      u8g2.setFont(u8g2_font_5x7_tf);
      u8g2.setCursor(2, 33);
      // Truncate patient name to 12-15 chars
      char displayName[16];
      strncpy(displayName, patientName, 15);
      displayName[15] = '\0';
      u8g2.print(displayName);
      u8g2.setFont(u8g2_font_4x6_tf);
      u8g2.setCursor(12, 45);
      u8g2.print("Analyzing");
      drawSpinner(24, 55, 6);
      break;
    }
  }

  u8g2.sendBuffer();
}

void setup() {
  Serial.begin(115200);
  delay(500);
  analogReadResolution(12);

  // Queue carries completed sample batches from the sampling task to loop().
  // Sized to buffer plenty of batches so none are lost during display/BLE work.
  batchQueue = xQueueCreate(64, sizeof(SampleBatch));

  // Create the sampling task before any timer can notify it. The timer ISR
  // notifies this task; the task performs the actual analogRead() sampling.
  xTaskCreatePinnedToCore(samplingTask, "sampling", 4096, NULL, 5, &samplingTaskHandle, 1);

  u8g2.begin();
  currentState = STATE_INITIALIZING;

  // Initialize BLE
  BLEDevice::init("PCG_Monitor_Raw");
  pServer = BLEDevice::createServer();
  pServer->setCallbacks(new ServerCallbacks());

  BLEService* pService = pServer->createService(SERVICE_UUID);
  pCharacteristic = pService->createCharacteristic(
    CHARACTERISTIC_UUID,
    BLECharacteristic::PROPERTY_READ | BLECharacteristic::PROPERTY_WRITE_NR | BLECharacteristic::PROPERTY_NOTIFY
  );
  pCharacteristic->setAccessPermissions(ESP_GATT_PERM_READ | ESP_GATT_PERM_WRITE);
  pCharacteristic->setCallbacks(new CharacteristicCallbacks());

  // Add CCCD descriptor for notifications
  BLE2902* pBLE2902 = new BLE2902();
  pBLE2902->setNotifications(true);
  pCharacteristic->addDescriptor(pBLE2902);

  pService->start();

  BLEAdvertising* pAdvertising = BLEDevice::getAdvertising();
  pAdvertising->addServiceUUID(SERVICE_UUID);
  pAdvertising->setScanResponse(true);
  pAdvertising->setMinPreferred(0x06);
  BLEDevice::startAdvertising();

  Serial.println("BLE: Advertising started");

  // Brief initialization animation, then go idle
  currentState = STATE_IDLE;
}

void loop() {
  // Set up timer if needed (deferred from BLE callback to avoid watchdog issues)
  if (shouldStartTimer) {
    shouldStartTimer = false;
    if (timer != NULL) {
      timerEnd(timer);
    }
    int timerIntervalUs = 1000000 / sampleRate;
    timer = timerBegin(TIMER_ID, TIMER_PRESCALER, TIMER_COUNT_UP);
    timerAttachInterrupt(timer, &onTimer, true);
    timerAlarmWrite(timer, timerIntervalUs, true);
    timerAlarmEnable(timer);
    Serial.println("Timer started in main loop");
  }

  // Check if analysis time has expired
  if (isAnalyzing && (millis() - analysisStartTime) > (analysisTimeSeconds * 1000UL)) {
    isAnalyzing = false;
    if (timer != NULL) {
      timerEnd(timer);
      timer = NULL;
    }
    currentState = STATE_CONNECTED;
    Serial.println("Analysis finished");
  }

  // Drain ALL completed batches from the sampling task and send them over BLE.
  // Emptying the queue every loop keeps up even when a single iteration is slow
  // (e.g. an OLED redraw), so no samples back up or get dropped.
  SampleBatch outBatch;
  while (xQueueReceive(batchQueue, &outBatch, 0) == pdTRUE) {
    if (deviceConnected) {
      pCharacteristic->setValue((uint8_t*)outBatch.samples, outBatch.count * sizeof(uint16_t));
      pCharacteristic->notify();
    }
  }

  // Throttle the OLED: its slow I2C writes would otherwise bottleneck BLE.
  static unsigned long lastDisplay = 0;
  if (millis() - lastDisplay >= 150) {
    lastDisplay = millis();
    updateDisplay();
  }

  delay(2);
}

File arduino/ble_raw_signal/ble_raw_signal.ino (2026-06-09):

#include <BLEDevice.h>
#include <BLEServer.h>
#include <BLEUtils.h>
#include <BLE2902.h>

// --- Configuration ---
const int ANALOG_PIN = A0;
const int SAMPLE_RATE = 500;
const int TIMER_INTERVAL_US = 1000000 / SAMPLE_RATE;

const int OVERSAMPLE_COUNT = 8;
const int BATCH_SIZE = 6;

// BLE UUIDs
#define SERVICE_UUID        "12345678-1234-1234-1234-123456789abc"
#define CHARACTERISTIC_UUID "abcd1234-ab12-cd34-ef56-123456789abc"

volatile uint16_t sampleBuffer[BATCH_SIZE];
volatile int sampleIndex = 0;
volatile bool batchReady = false;

// 12-byte payload for raw signal
uint16_t sendBuffer[BATCH_SIZE];

BLEServer* pServer = NULL;
BLECharacteristic* pCharacteristic = NULL;
bool deviceConnected = false;
hw_timer_t* timer = NULL;

// --- BLE Callbacks ---
class ServerCallbacks : public BLEServerCallbacks {
  void onConnect(BLEServer* pServer) {
    deviceConnected = true;
    Serial.println("Client connected");
  }
  void onDisconnect(BLEServer* pServer) {
    deviceConnected = false;
    Serial.println("Client disconnected");
    BLEDevice::startAdvertising();
  }
};

// --- Interrupt Service Routine ---
void ARDUINO_ISR_ATTR onTimer() {
  if (batchReady) return;

  uint32_t sum = 0;
  for (int i = 0; i < OVERSAMPLE_COUNT; i++) {
    sum += analogRead(ANALOG_PIN);
  }
  sampleBuffer[sampleIndex] = sum / OVERSAMPLE_COUNT;
  sampleIndex++;

  if (sampleIndex >= BATCH_SIZE) {
    sampleIndex = 0;
    batchReady = true;
  }
}

void setup() {
  Serial.begin(115200);
  analogReadResolution(12);

  BLEDevice::init("PCG_Monitor_Raw");
  pServer = BLEDevice::createServer();
  pServer->setCallbacks(new ServerCallbacks());

  BLEService* pService = pServer->createService(SERVICE_UUID);
  pCharacteristic = pService->createCharacteristic(
    CHARACTERISTIC_UUID,
    BLECharacteristic::PROPERTY_NOTIFY
  );
  pCharacteristic->addDescriptor(new BLE2902());
  pService->start();

  BLEAdvertising* pAdvertising = BLEDevice::getAdvertising();
  pAdvertising->addServiceUUID(SERVICE_UUID);
  pAdvertising->setScanResponse(true);
  pAdvertising->setMinPreferred(0x06);
  BLEDevice::startAdvertising();

  Serial.println("BLE advertising started (Raw Signal Mode)...");

  timer = timerBegin(0, 80, true);
  timerAttachInterrupt(timer, &onTimer, true);
  timerAlarmWrite(timer, TIMER_INTERVAL_US, true);
  timerAlarmEnable(timer);
}

void loop() {
  if (batchReady && deviceConnected) {

    uint16_t localRaw[BATCH_SIZE];
    noInterrupts();
    memcpy(localRaw, (const void*)sampleBuffer, BATCH_SIZE * sizeof(uint16_t));
    batchReady = false;
    interrupts();

    // Send raw signal directly without any filtering
    for (int i = 0; i < BATCH_SIZE; i++) {
      sendBuffer[i] = localRaw[i];
    }

    // Send exactly 12 bytes
    pCharacteristic->setValue((uint8_t*)sendBuffer, BATCH_SIZE * sizeof(uint16_t));
    pCharacteristic->notify();

  } else if (batchReady && !deviceConnected) {
    batchReady = false;
  }
}

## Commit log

2026-05-18 Implemetening filter to arduino code v1
2026-06-09 add lcd test code for arduino
2026-06-09 arduino: scaffold BLE LCD analyzer sketch
2026-06-09 arduino: add LCD display with state rendering
2026-06-09 arduino: implement BLE server with state callbacks
2026-06-09 arduino: implement BLE command parser and timer-based sampling
2026-06-09 docs: add comprehensive Arduino wiring guide
2026-06-09 fix: separate battery (A0) and signal (A1) inputs - prevent interference
    [ble_lcd_analyzer.ino]
2026-06-09 fix: update I2C pins for Arduino Nano ESP32 (A4/A5 instead of D4/D5)
    [ble_lcd_analyzer.ino]
2026-06-09 fix: add explicit BLE write permissions and READ property
    [ble_lcd_analyzer.ino]
2026-06-09 fix: properly configure BLE2902 descriptor for notifications
    [ble_lcd_analyzer.ino]
2026-06-14 add box design
    [Part1.SLDPRT, Part1.STEP, Part1.STL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]
2026-06-22 Add files via upload
    Add outputs
    [Bill of Materials-PCB_Project_Stethoscope.xlsx]
